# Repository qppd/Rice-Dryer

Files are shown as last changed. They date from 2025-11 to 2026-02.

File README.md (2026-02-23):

# RiceDryer ESP32 & Android IoT System

IoT-enabled Rice Dryer system with ESP32 hardware and Android application for remote monitoring and control via Firebase Realtime Database.

## Table of Contents

1. [Features](#features)
2. [Quick Start](#quick-start)
3. [System Architecture](#system-architecture)
4. [Hardware Components](#hardware-components)
5. [3D Models](#3d-models)
6. [Software Components](#software-components)
6. [Security and Credentials](#security-and-credentials)
7. [Installation Guide](#installation-guide)
8. [Device Pairing](#device-pairing)
9. [Usage Instructions](#usage-instructions)
10. [Code Structure](#code-structure)
11. [Firebase Database Structure](#firebase-database-structure)
12. [Android Application](#android-application)
13. [NTP Time Synchronization](#ntp-time-synchronization)
14. [Testing](#testing)
15. [Troubleshooting](#troubleshooting)
16. [Development Roadmap](#development-roadmap)
17. [Technical Specifications](#technical-specifications)
18. [Contributing](#contributing)
19. [License](#license)
20. [Contact](#contact)

## Features

### ESP32 Core Features

#### Hardware Control
- **3-Button Interface**: Setting mode toggle, start/stop control, WiFi reset functionality
- **Remote Setpoint Control**: Temperature/humidity setpoint adjustment via Android app (30-80°C, 10-50%)
- **Dual Relay System**: Independent heater (SSR1) and fan (SSR2) control for optimal drying
- **Smart Drying Logic**: Auto-stop when humidity target reached, PID temperature control
- **Safety Features**: Sensor error detection, force-stop capability, confirmation dialogs

#### Connectivity & Communication
- **WiFiManager Integration**: Easy WiFi configuration through captive portal (SSID: "RiceDryer_Setup")
- **Firebase Realtime Database**: Automatic device registration and real-time data synchronization
- **NTP Time Sync**: Network Time Protocol for accurate timestamps (Philippines timezone UTC+8)
- **Real-time Data Streaming**: Updates every 5 seconds (temperature, humidity, both setpoints, relay status)
- **Historical Data Logging**: Comprehensive sensor readings logged every 30 seconds
- **Remote Control**: Responds to START, STOP, SET_TEMP, SET_HUMIDITY commands
- **Device Pairing**: Secure 6-digit pairing code generation and validation

#### User Interface & Experience
- **Multi-Mode LCD Display**: Normal operation, setting modes, pairing mode, WiFi setup
- **Interactive Setting Modes**: Temperature setting mode, humidity setting mode with visual feedback
- **Mode Timeout Protection**: Auto-return to normal mode after 5 seconds of inactivity
- **Button Debouncing**: Reliable 200ms debounce for all button interactions
- **Status Indicators**: Real-time drying status, connectivity status, error notifications

#### Advanced Features
- **OTA Updates Support**: Over-the-air firmware updates with progress display
- **Automatic Reconnection**: Exponential backoff for WiFi and Firebase connections
- **Test Mode**: Component testing suite accessible at startup
- **WiFi Credential Reset**: Hold-to-confirm WiFi reset (3-second hold protection)
- **Sensor Validation**: DHT22 error detection with user notification

### Android App Features (95% Complete ✅)

- **Authentication System**: Email/password login, registration, password reset, session management
- **Multi-Device Support**: Manage multiple rice dryers from single account
- **Dashboard**: Real-time temperature/humidity gauges with animations, device status, heater/fan control
- **Charts and Analytics**: Interactive line charts with zoom/pan, time range filters (1h, 6h, 24h, 1 week), statistics
- **Device List Management**: View all paired devices, connection status, last update time
- **Device Pairing**: Secure 6-digit code pairing with validation and expiry check
- **Real-time Updates**: Firebase listeners for live data synchronization
- **Offline Support**: Local caching with Room database for offline access
- **Material Design 3**: Modern, professional UI following Material Design guidelines
- **Navigation**: Jetpack Compose Navigation with type-safe routing
- **Dark Theme Support**: Full Material You dynamic theming

## Quick Start

### Prerequisites

Hardware:
- ESP32 Development Board (38-pin dev module)
- DHT22 Temperature & Humidity Sensor
- 16x2 I2C LCD Display
- 2x Solid State Relays (SSR) - Heater (SSR1) + Fan (SSR2) control
- 3x Push Buttons (setting mode, start/stop, WiFi reset)
- Power supply and connecting wires
- Pull-up resistors (or use ESP32 internal pull-ups)

Software:
- Arduino IDE (1.8.19 or higher) OR PlatformIO
- Android Studio (latest version with Compose support)
- Firebase Account with Realtime Database enabled
- Git

### ESP32 Quick Setup

1. Clone Repository:
```bash
git clone https://github.com/qppd/Rice-Dryer.git
cd Rice-Dryer
```

2. Setup Firebase Credentials:
```bash
cd source/esp32/RiceDryer
copy FirebaseConfig.cpp.template FirebaseConfig.cpp
copy FirebaseConfig.h.template FirebaseConfig.h
```

3. Edit FirebaseConfig.cpp and FirebaseConfig.h with your Firebase credentials:
   - Get from Firebase Console > Project Settings > Service accounts
   - Update Firebase host, auth token, and database URL

4. Install Required Libraries in Arduino IDE:
   - WiFiManager by tzapu (v2.0.16-rc.2 or higher)
   - Firebase ESP32 Client by Mobizt (v4.4.14 or higher)
   - DHT sensor library by Adafruit (v1.4.6 or higher)
   - LiquidCrystal I2C (v1.1.2 or higher)
   - ArduinoJson (v6.21.5 or higher)

5. Configure Arduino IDE:
   - Board: ESP32 Dev Module
   - **Partition Scheme: "Minimal SPIFFS (1.9MB APP)" or "Huge APP (3MB No OTA)"** ⚠️ **CRITICAL**
   - Upload Speed: 921600
   - Flash Size: 4MB
   - Flash Mode: QIO
   - Flash Frequency: 80MHz

   **⚠️ IMPORTANT: Partition Scheme Selection**
   
   The default partition scheme (1.3MB APP) is **too small** for Firebase projects. You MUST change it:
   
   **For Arduino IDE 1.x:**
   - Go to Tools → Partition Scheme
   - Select "Minimal SPIFFS (1.9MB APP)" or "Huge APP (3MB No OTA)"
   
   **For Arduino IDE 2.x (if Partition Scheme not visible):**
   - See detailed instructions in "Arduino IDE 2.x Partition Fix" section below
   
   **Why this is required:**
   - Firebase ESP32 Client library is large (~150KB)
   - WiFiManager adds ~80KB
   - Total sketch size: ~420KB (32% of 1.3MB, 13% of 3MB)
   - Recommended: Use "Huge APP (3MB No OTA)" for maximum space

6. Upload to ESP32:
   - Open RiceDryer.ino in Arduino IDE
   - Verify/Compile (Ctrl+R)
   - Upload (Ctrl+U)

7. First Boot Sequence:
   - ESP32 creates WiFi AP: "RiceDryer_Setup" (password: password123)
   - Connect to AP from phone/computer
   - Captive portal opens automatically
   - Configure your WiFi credentials
   - ESP32 syncs time via NTP (Philippines timezone)
   - Firebase connection established
   - 6-digit pairing code displayed on LCD

### Android Quick Setup

1. Navigate to Android project:
```bash
cd source/android/RiceDryer
```

2. Setup Firebase for Android:
   - Get google-services.json from Firebase Console > Project Settings
   - Place in: `source/android/RiceDryer/app/google-services.json`

3. Open in Android Studio:
   - File > Open > select `source/android/RiceDryer` folder
   - Wait for Gradle sync to complete
   - Build > Rebuild Project

4. Run on Device/Emulator:
   - Connect Android device via USB (enable USB debugging)
   - Or start Android emulator
   - Run > Run 'app' (Shift+F10)
   - Register new account or login
   - Pair device using 6-digit code from LCD

### Verification Checklist

✅ Verify credentials are protected:
```bash
git status
# Should NOT show FirebaseConfig.cpp, FirebaseConfig.h, or google-services.json
```

✅ ESP32 Tests:
- LCD displays WiFi connected and IP address
- LCD shows "Time Synced" with current date/time (Philippines timezone)
- Firebase Ready message appears
- Pairing code (6 digits) displayed on LCD
- Temperature and humidity readings updating

✅ Android Tests:
- Login/Registration works
- Device pairing successful
- Dashboard shows real-time temperature/humidity
- START/STOP commands work
- Charts display historical data
- Device list shows paired devices

## System Architecture

The Rice Dryer system follows a modern IoT architecture with five distinct layers:

### 1. Hardware Layer
- ESP32 microcontroller (38-pin dev module)
- DHT22 temperature and humidity sensor
- 16x2 I2C LCD display (0x27 address)
- 2x Solid State Relays (Heater on GPIO 26, Fan on GPIO 27)
- 3x Push buttons with debouncing

### 2. Firmware Layer (ESP32)
- Arduino C++ based firmware
- WiFiManager for network configuration
- Firebase ESP32 Client for cloud connectivity
- NTP time synchronization (Philippines UTC+8)
- PID temperature controller
- Real-time sensor reading and control logic

### 3. Cloud Layer (Firebase)
- Firebase Realtime Database for data storage and synchronization
- Firebase Authentication for user management
- Secure device pairing mechanism
- Real-time data streaming
- Historical data storage (30-second intervals)

### 4. Application Layer (Android)
- Kotlin with Jetpack Compose
- MVVM architecture pattern
- Repository pattern for data management
- Kotlin Coroutines and Flow for async operations
- Room database for local caching
- Material Design 3 UI components

### 5. User Interface Layer
- Dashboard with animated circular gauges

- Historical data charts
- Device management interface
- Profile and settings

## Hardware Components

### Complete Bill of Materials

The Rice Dryer system consists of the following components, organized by category:

#### 🔧 Electronics & Control

**Microcontroller & Development:**
- ESP32 38-pin Development Board
  - Clock Speed: 240 MHz dual-core
  - Flash Memory: 4MB
  - WiFi: 802.11 b/g/n
  - Operating Voltage: 3.3V
  - Source: [ESP32 38-pin Dev Board](https://www.lazada.com.ph/products/pdp-i229344573-s15172858004.html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)

**Sensors:**
- DHT22 Temperature & Humidity Sensor
  - Temperature Range: -40°C to 80°C (±0.5°C accuracy)
  - Humidity Range: 0-100% RH (±2-5% accuracy)
  - Sampling Rate: 0.5 Hz (once every 2 seconds)
  - Source: [DHT22 Sensor](https://www.lazada.com.ph/products/pdp-i132179919.html)

**Display:**
- I2C LCD 20x4 Display
  - Display: 20 characters x 4 lines
  - Backlight: Blue LED
  - Interface: I2C (SDA, SCL)
  - Address: 0x27 or 0x3F
  - Source: [I2C LCD 20x4](https://www.lazada.com.ph/products/pdp-i230446570-s1630476280.html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)

**Control Components:**
- 2x 1-Channel Relay Modules with Optocoupler
  - Control Voltage: 3-32V DC
  - Load Voltage: 5-250V AC/DC
  - Load Current: 10A maximum
  - Isolation: Optocoupler protection
  - Source: [1-Channel Relay Module](https://www.lazada.com.ph/products/pdp-i100047427-s100061336.html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)
- 10K Potentiometer (Linear)
  - Resistance: 10KΩ
  - Type: Rotary potentiometer
  - Usage: Temperature/humidity setpoint adjustment
- 3x Push Button Switches (Momentary)
  - Type: SPST momentary contact
  - Rating: 12V/1A
  - Usage: Control interface buttons
  - Source: [Tactile Push Buttons](https://www.lazada.com.ph/products/pdp-i1678078643-s7245702074.html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)

#### ⚡ Power & Heating System

**Heating & Ventilation:**
- 2x 12V Exhaust Fans
  - Model: HF DC BRUSHLESS FAN 120mm DF1202512SEL
  - Voltage: 12V DC
  - Current: 0.16A each
  - Power: 1.92W each
  - Airflow: 50 CFM (estimated)
  - Source: [HF DC BRUSHLESS FAN 120mm](https://www.lazada.com.ph/products/pdp-i3534864736.html)
  - Usage: Air circulation and moisture removal
- 12V Heating Element (Salvaged and Modified)
  - Voltage: 12V DC
  - Power: 35W (tested)
  - Type: Modified car hair dryer heating element (2 elements remaining from original 6)
  - Source: [12V Car Folding Hair Drier](https://www.lazada.com.ph/products/i4960365287-s28954002950.html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)
  - Usage: Primary heating source

**Power Management:**
- MPPT Solar Charge Controller
  - Model: MPPT 30A/50A/100A 12V/24V Auto Focus Tracking Solar Panel Charge Controller Regulator with Dual
  - Input Voltage: 12-150V DC (estimated)
  - Output Voltage: 12V/24V DC
  - Current Options: 30A, 50A, 100A
  - Type: MPPT (Maximum Power Point Tracking)
  - Efficiency: High efficiency auto focus tracking
  - Source: [MPPT Solar Charge Controller](https://www.lazada.com.ph/products/pdp-i4841729811-s28068159465.html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)
  - Usage: Solar panel charge regulation for battery charging
- 12V Deep Cycle Gel Battery
  - Model: High-Quality 12V Deep Cycle Gel E-Bike Battery 16AH/25AH for Scooters and Motorcycles
  - Voltage: 12V
  - Capacity Options: 16AH, 25AH
  - Type: Sealed lead-acid gel battery (deep cycle)
  - Cycle Life: High cycle life for deep discharge
  - Source: [12V Gel Battery](https://www.lazada.com.ph/products/high-quality-12v-deep-cycle-gel-e-bike-battery-16ah25ah-for-scooters-and-motorcycles-i4913678464-s28636228269.html)
  - Usage: Energy storage for the 12V system
- SPST KCD11 Miniature Rocker Switch
  - Model: SPST KCD11 Miniature Rocker Switch - 5Pcs
  - Type: SPST rocker switch (2 Pin or 3 Pin options)
  - Rating: 12V/10A (estimated)
  - Illumination: Red LED indicator (if applicable)
  - Quantity: 5 pieces
  - Source: [Rocker Switch](https://www.lazada.com.ph/products/pdp-i3015510213-s14819033850.html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)
  - Usage: Power switch for the 12V system
- 12V Power Adapter
  - Output Options: 12V 2A
  - Type: True rated power adapter
  - Source: [12V 2A Power Adapter](https://www.lazada.com.ph/products/i136286593-s153295621.html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)
  - Usage: Main power supply for 12V system

#### 🏗️ Mechanical & Enclosure

**Structural Materials:**
- 1/2" Nebraska Plywood Sheets
  - Thickness: 12mm (1/2 inch)
  - Size: 4ft x 8ft sheets
  - Type: Marine-grade plywood
  - Usage: Main enclosure construction
- Tek Screws (Assorted)
  - Sizes: #6, #8, #10
  - Length: 1/2" to 2"
  - Type: Self-tapping screws
  - Quantity: 200 pieces
- Nails (Assorted)
  - Sizes: 1", 1.5", 2"
  - Type: Common nails
  - Quantity: 500 pieces

**Prototyping:**
- Perf Board (Prototype Board)
  - Size: 2" x 3"
  - Hole Pattern: 0.1" grid
  - Copper Pads: Plated through holes
  - Usage: Custom circuit prototyping
  - Source: [Perf Board](https://www.lazada.com.ph/products/pdp-i4835206547-s28752341734.html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)

### Wiring Diagram

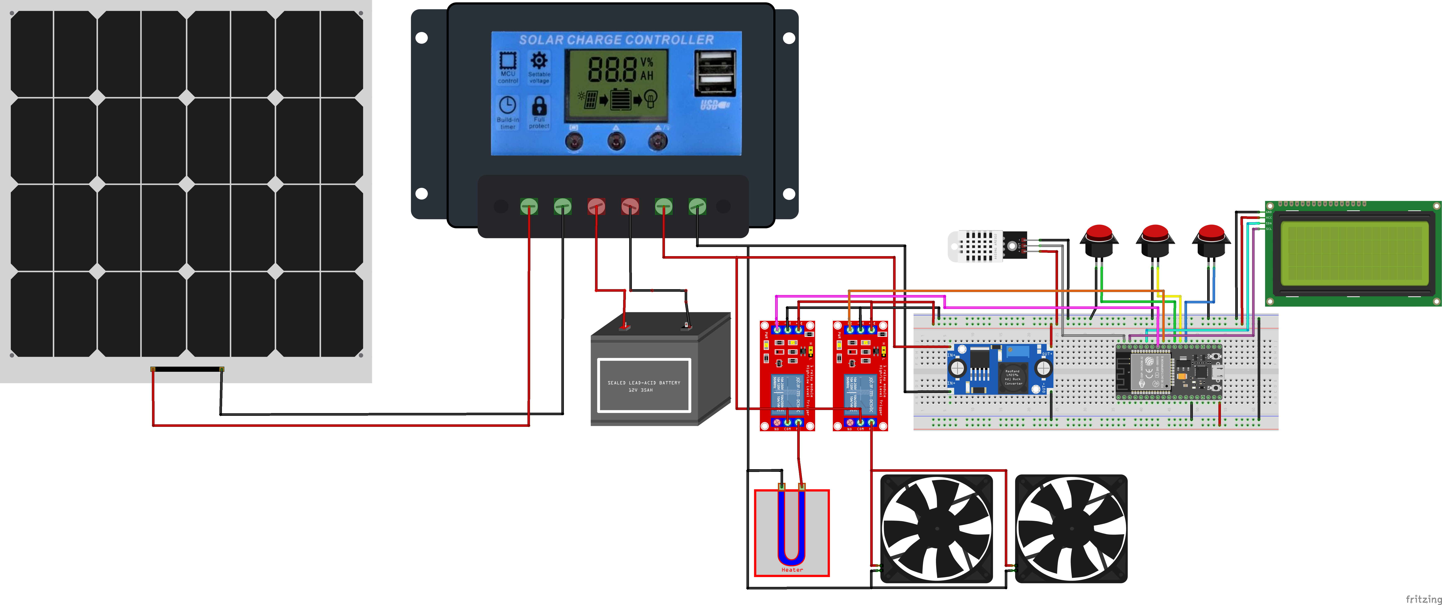
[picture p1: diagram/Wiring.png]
Rice Dryer Wiring Diagram


**Download Fritzing File:** [Wiring.fzz](diagram/Wiring.fzz)

### MakerLab Electronics Components

The following components were sourced from [MakerLab Electronics](https://makerlab-electronics.com) and are available on Lazada Philippines:

**✅ Available at MakerLab on Lazada:**
- [ESP32 38-pin Development Board](https://www.lazada.com.ph/products/pdp-i229344573.html)
- [DHT22 Temperature & Humidity Sensor](https://www.lazada.com.ph/products/pdp-i132179919.html)
- [I2C LCD 20x4 Display](https://www.lazada.com.ph/products/pdp-i230446570.html)
- [1-Channel Relay Modules with Optocoupler (2x required)](https://www.lazada.com.ph/products/pdp-i100047427.html)

- [Push Button Switches (3x required)](https://www.lazada.com.ph/products/pdp-i3015053765.html)

### Cost Estimate & Sourcing

**Estimated Total Cost: ₱8,170 - ₱11,500**

**By Component Category:**

**Electronics (MakerLab): ₱2,500 - ₱3,500**
- ESP32 Dev Board: ₱450
- DHT22 Sensor: ₱150
- 20x4 I2C LCD: ₱350
- 2x Relay Modules: ₱200 each = ₱400
- 10K Potentiometer: ₱25
- 3x Push Buttons: ₱15 each = ₱45
- Perf Board: ₱50

**Power & Heating System: ₱4,000 - ₱6,000**
- 2x 12V Exhaust Fans: ₱250 each = ₱500
- 12V Heating Element: ₱800
- 12V Solar Charge Controller: ₱1,200
- 12V 16AH Gel Battery: ₱2,500
- Rocker Switch: ₱50

**Mechanical & Enclosure: ₱1,670 - ₱2,000**
- 1/2" Nebraska Plywood (4x8 sheet): ₱980
- Tek Screws (assorted): ₱50
- Nails (assorted): ₱50
- Hinges (2 pcs): ₱70 each = ₱140
- Miscellaneous hardware: ₱450

### Main Components

ESP32 Development Module:
- Clock Speed: 240 MHz dual-core
- Flash Memory: 4MB
- WiFi: 802.11 b/g/n
- Operating Voltage: 3.3V

DHT22 Temperature and Humidity Sensor:
- Temperature Range: -40°C to 80°C (±0.5°C accuracy)
- Humidity Range: 0-100% RH (±2-5% accuracy)
- Sampling Rate: 0.5 Hz (once every 2 seconds)

16x2 I2C LCD Display:
- Display: 20 characters x 4 lines
- Backlight: Blue LED
- Interface: I2C (SDA, SCL)
- Address: 0x27 or 0x3F
- Note: System uses 20x4 LCD for enhanced display

Solid State Relay (SSR):
- Control Voltage: 3-32V DC
- Control Current: 5-25 mA
- Load Voltage: 24-380V AC
- Load Current: 25A continuous
- Switching Time: 10ms
- Zero-crossing: Yes
- Trigger Type: Low trigger (active low)

Additional Components:
- Push Button: Manual control and mode selection
- Power Supply: 5V/2A for ESP32 and peripherals
- Solar Panel (Optional): 12V/10W for off-grid operation

### Pin Connections (PinConfig.h) - Updated Configuration

DHT22 Sensor:
- VCC  -> 3.3V
- GND  -> GND
- DATA -> GPIO 39 (Input-only, perfect for sensor)

LCD (I2C):
- VCC -> 5V
- GND -> GND
- SDA -> GPIO 21
- SCL -> GPIO 22

Relay Controls:
- Relay 1 (Main Heater) -> GPIO 19
- Relay 2 (Fan/Secondary) -> GPIO 18
- VCC -> 3.3V/5V (depending on relay module)
- GND -> GND

Control Buttons:
- Button 1 (Setting Mode) -> GPIO 17 + GND (internal pull-up)
- Button 2 (Start/Stop) -> GPIO 16 + GND (internal pull-up)
- Button 3 (WiFi Reset) -> GPIO 4 + GND (internal pull-up)

## 3D Models

The Rice Dryer features a professional 3D-designed enclosure with optimized component placement and airflow design.

### Enclosure Views

#### Full Assembly Views
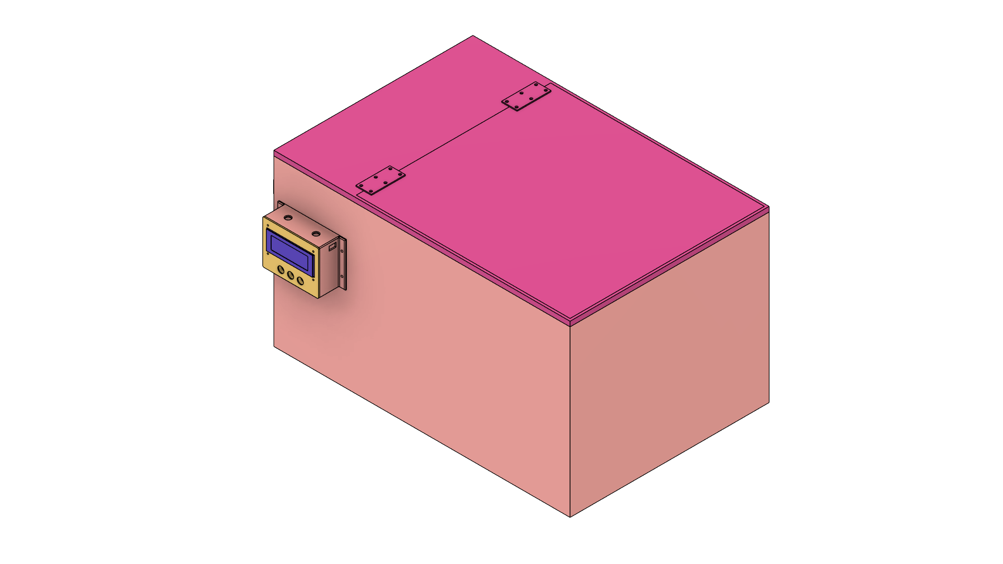
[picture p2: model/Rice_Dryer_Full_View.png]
Rice Dryer Full View

*Complete assembly with all components installed*

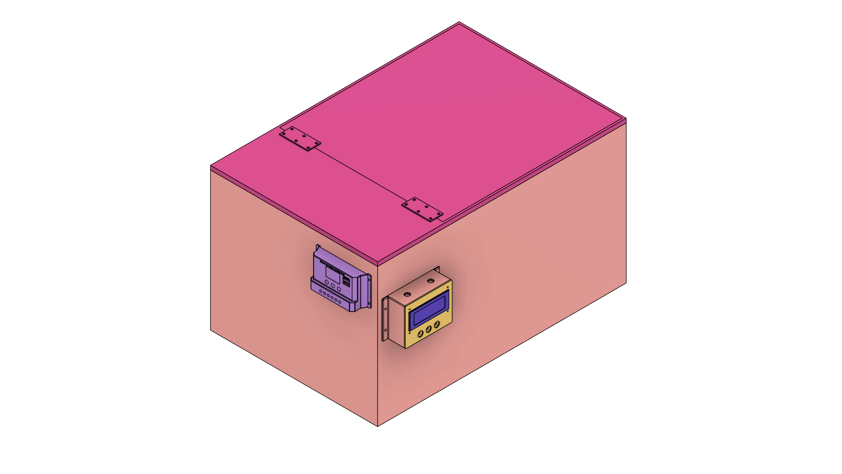
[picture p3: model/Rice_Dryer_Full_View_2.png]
Rice Dryer Full View 2

*Alternative full view showing different angle*

#### Internal Component Views
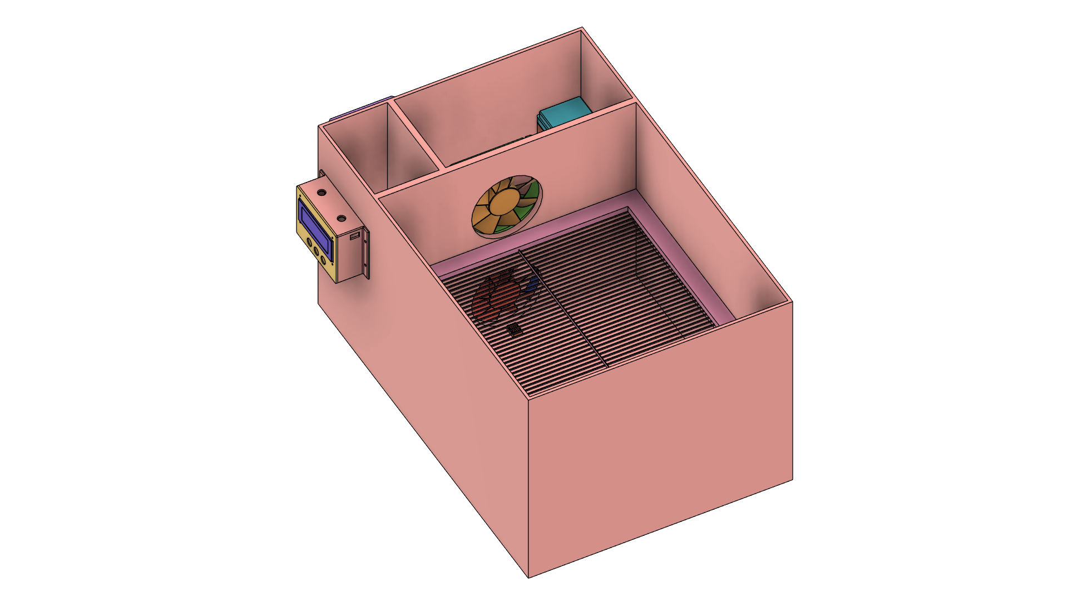
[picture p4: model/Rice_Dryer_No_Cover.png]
Rice Dryer No Cover

*Internal layout without top cover*

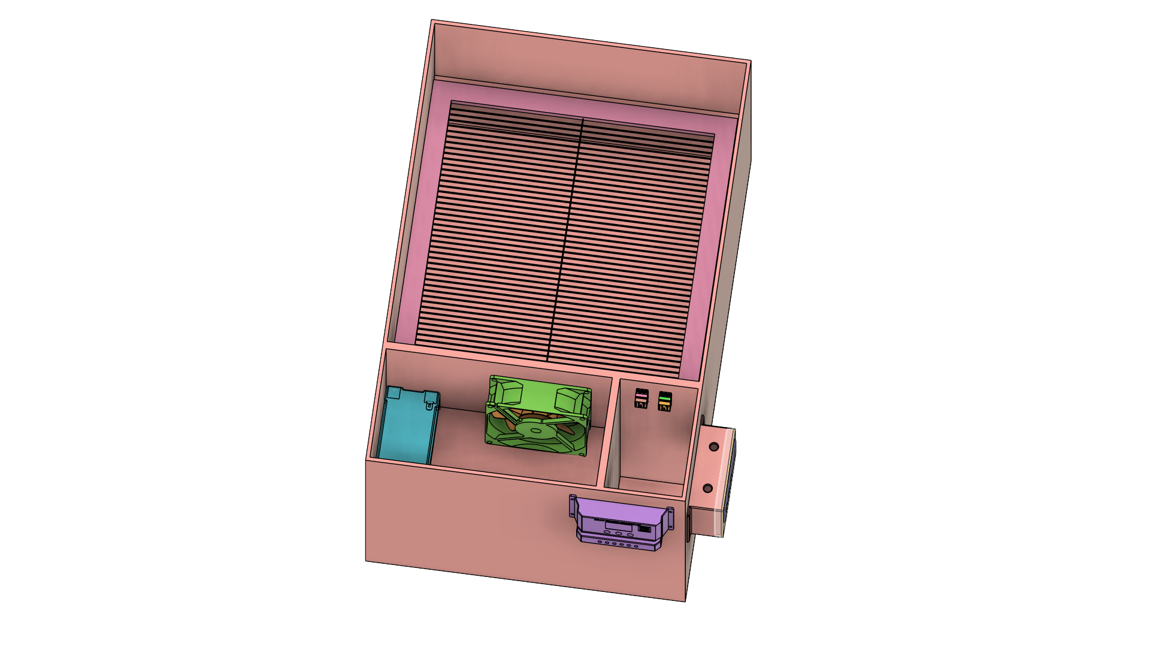
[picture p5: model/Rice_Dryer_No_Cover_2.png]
Rice Dryer No Cover 2

*Detailed internal component arrangement*

#### Orthogonal Views
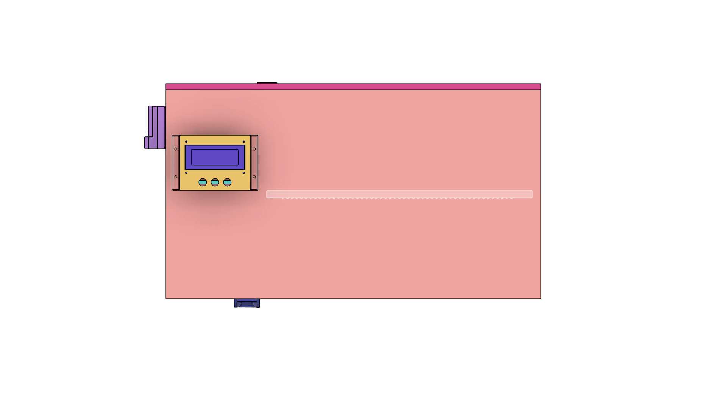
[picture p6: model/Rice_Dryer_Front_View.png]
Rice Dryer Front View

*Front elevation view*

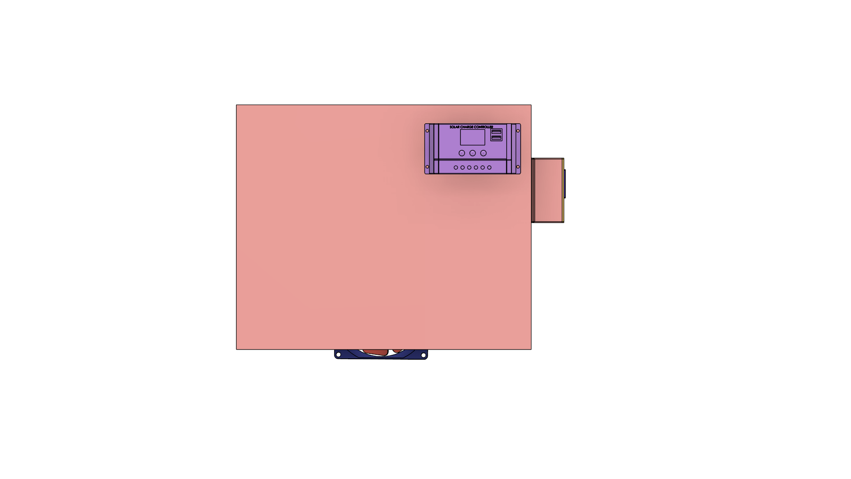
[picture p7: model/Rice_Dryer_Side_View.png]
Rice Dryer Side View

*Side elevation view*

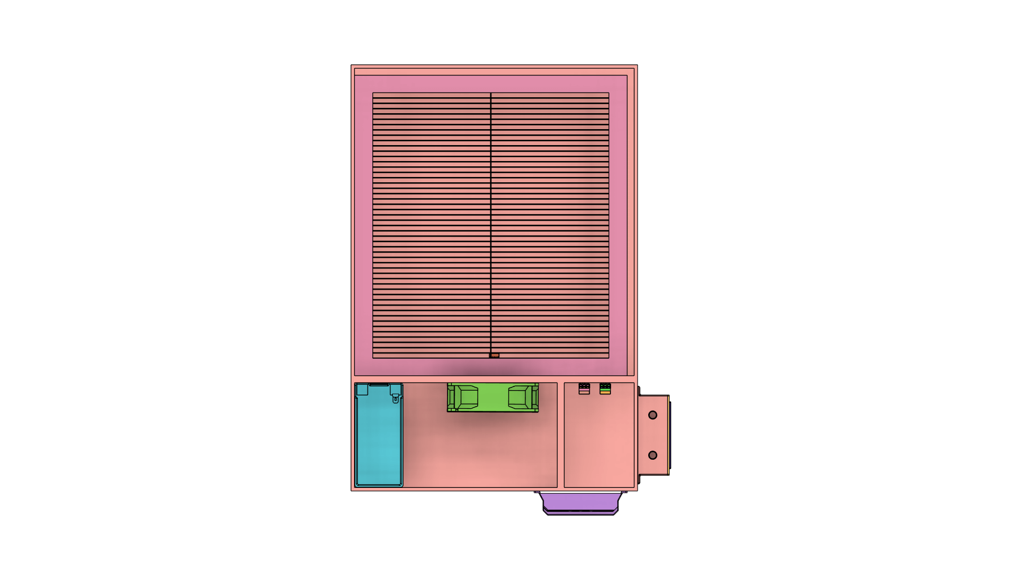
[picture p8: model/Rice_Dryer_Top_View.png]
Rice Dryer Top View

*Top plan view*

### Design Features

- **Optimized Airflow**: Strategic fan placement for efficient moisture removal
- **Component Accessibility**: Easy access panels for maintenance
- **Professional Finish**: Clean aesthetic with functional design
- **Modular Construction**: Easy assembly and disassembly
- **Thermal Management**: Proper ventilation for electronic components

## Software Components

### ESP32 Libraries

Core Libraries:
- WiFi.h (built-in): WiFi connectivity
- WiFiManager.h: Captive portal configuration
- Firebase_ESP_Client.h: Firebase integration
- ArduinoOTA.h (built-in): Over-the-air updates
- ArduinoJson.h: JSON parsing

Sensor Libraries:
- DHT.h: DHT22 sensor interface
- LiquidCrystal_I2C.h: LCD display control

Custom Modules:
- FirebaseConfig: Credential management
- WiFiManagerCustom: WiFi connection wrapper
- Button: Button debouncing and state management
- DHT22Sensor: Temperature/humidity reading
- SSR: Relay control
- LCDDisplay: Display management

### Android Dependencies

Core Android:
- androidx.appcompat:appcompat:1.6.1
- com.google.android.material:material:1.11.0
- androidx.constraintlayout:constraintlayout:2.1.4

Firebase (BOM 32.7.0):
- firebase-auth: User authentication
- firebase-database: Realtime Database
- firebase-messaging: Push notifications
- firebase-analytics: Usage tracking
- firebase-crashlytics: Crash reporting

Architecture Components:
- lifecycle-viewmodel:2.7.0
- lifecycle-livedata:2.7.0
- navigation-fragment:2.7.6
- navigation-ui:2.7.6

Database:
- room-runtime:2.6.1
- room-compiler:2.6.1

Charts and UI:
- MPAndroidChart:v3.1.0
- Lottie:6.3.0
- Glide:4.16.0
- Shimmer:0.5.0

### Project Structure

```
Rice-Dryer/
├── source/
│   ├── esp32/
│   │   ├── .gitignore
│   │   └── RiceDryer/
│   │       ├── RiceDryer.ino
│   │       ├── FirebaseConfig.cpp (gitignored)
│   │       ├── FirebaseConfig.h (gitignored)
│   │       ├── FirebaseConfig.cpp.template
│   │       ├── FirebaseConfig.h.template
│   │       ├── WiFiManagerCustom.cpp
│   │       ├── WiFiManagerCustom.h
│   │       ├── Button.cpp/h
│   │       ├── DHT22Sensor.cpp/h
│   │       ├── LCDDisplay.cpp/h
│   │       ├── SSR.cpp/h
│   │       └── PinConfig.h
│   │
│   └── android/
│       ├── .gitignore
│       └── app/
│           ├── build.gradle
│           ├── google-services.json (gitignored)
│           ├── google-services.json.template
│           └── src/main/java/com/qppd/ricedryer/
│               ├── data/
│               │   ├── model/
│               │   │   ├── User.java
│               │   │   ├── Device.java
│               │   │   ├── SensorReading.java
│               │   │   └── Command.java
│               │   ├── remote/
│               │   │   ├── FirebaseAuthManager.java
│               │   │   └── FirebaseDataSource.java
│               │   └── repository/
│               │       ├── AuthRepository.java
│               │       └── DeviceRepository.java
│               ├── ui/
│               │   ├── auth/
│               │   │   ├── LoginActivity.java
│               │   │   ├── AuthViewModel.java
│               │   │   └── activity_login.xml
│               │   └── [other activities/fragments]
│               └── utils/
│                   ├── Constants.java
│                   ├── DateUtils.java
│                   └── ValidationUtils.java
│
├── .gitignore
├── README.md
└── [documentation files]
```

## Security and Credentials

### Overview

This project implements enterprise-grade security with multi-layer protection for sensitive credentials. All API keys, Firebase credentials, and configuration files are properly protected from version control.

### Critical Files (NEVER COMMIT)

ESP32 Credentials:
- source/esp32/RiceDryer/FirebaseConfig.cpp
- source/esp32/RiceDryer/FirebaseConfig.h

Android Credentials:
- source/android/app/google-services.json
- source/android/app/*.keystore
- source/android/app/*.jks

### Multi-Layer Protection

We have implemented three levels of .gitignore protection:

Level 1 - Root .gitignore:
- Covers entire project
- Blocks all credential files globally
- Protects build artifacts and IDE files
- 200+ patterns for comprehensive coverage

Level 2 - ESP32 .gitignore:
- Located: source/esp32/.gitignore
- Blocks FirebaseConfig.cpp and FirebaseConfig.h
- Protects compiled binaries and build artifacts

Level 3 - Android .gitignore:
- Located: source/android/.gitignore
- Blocks google-services.json
- Protects keystore files and signing configurations

### Modular Architecture

Following the Smart Fan project pattern, credentials are separated into dedicated modules:

FirebaseConfig Module:
- FirebaseConfig.h: Method declarations
- FirebaseConfig.cpp: Implementation with actual credentials (gitignored)
- FirebaseConfig.h.template: Safe template for new developers
- FirebaseConfig.cpp.template: Safe template for new developers

Benefits:
- Credentials separated from main code
- Easy to update without touching main sketch
- Template files guide new developers
- Clean, professional code structure

### Setup Process for New Developers

1. Clone repository:
```bash
git clone https://github.com/qppd/Rice-Dryer.git
cd Rice-Dryer
```

2. Setup ESP32 credentials:
```bash
cd source/esp32/RiceDryer
copy FirebaseConfig.cpp.template FirebaseConfig.cpp
copy FirebaseConfig.h.template FirebaseConfig.h
```

3. Get credentials from Firebase Console:
   - Go to Project Settings
   - Download google-services.json
   - Extract values:
     - project_id
     - firebase_url
     - current_key (API key)

4. Edit FirebaseConfig.cpp:
```cpp
const char* FirebaseConfig::getFirebaseHost() {
    return "YOUR-PROJECT-default-rtdb.firebaseio.com";
}

const char* FirebaseConfig::getFirebaseAuth() {
    return "YOUR_API_KEY";
}

const char* FirebaseConfig::getDatabaseURL() {
    return "https://YOUR-PROJECT-default-rtdb.firebaseio.com";
}

const char* FirebaseConfig::getProjectId() {
    return "YOUR-PROJECT-ID";
}
```

5. Setup Android credentials:
   - Place google-services.json in: source/android/app/google-services.json

6. Verify protection:
```bash
git status
# FirebaseConfig.cpp and google-services.json should NOT appear
```

### Security Best Practices

DO:
- Use template files for credentials
- Keep credentials in .gitignore
- Share credentials through secure channels (not git)
- Rotate API keys regularly
- Use different credentials for dev/prod
- Verify .gitignore before committing

DON'T:
- Commit credential files to git
- Share credentials in public channels
- Hardcode credentials in source files
- Push google-services.json to remote
- Commit keystore files
- Use production keys in development

### Verification Commands

Check if credentials are tracked:
```bash
git ls-files | grep -E "(FirebaseConfig\.(cpp|h)|google-services\.json)"
# Should return NOTHING
```

Check git status:
```bash
git status
# Credential files should not appear
```

Verify .gitignore is working:
```bash
git check-ignore -v source/esp32/RiceDryer/FirebaseConfig.cpp
git check-ignore -v source/android/app/google-services.json
# Should show which .gitignore rule is blocking them
```

### Emergency: Credentials Exposed

If credentials are accidentally committed:

1. Immediately remove from git history:
```bash
git filter-branch --force --index-filter \
  "git rm --cached --ignore-unmatch path/to/credential/file" \
  --prune-empty --tag-name-filter cat -- --all
```

2. Regenerate all exposed credentials:
   - Go to Firebase Console
   - Regenerate API keys
   - Update all local copies
   - Inform team members

3. Force push (if using remote):
```bash
git push origin --force --all
```

### Pre-Commit Checklist

Before every commit:
- [ ] Run git status - no credential files
- [ ] Check diff with git diff - no API keys visible
- [ ] Verify .gitignore is updated
- [ ] Test build works with templates
- [ ] Review file list in git add

## Installation Guide

### ESP32 Installation

1. Install Arduino IDE:
   - Download from arduino.cc
   - Install version 1.8.19 or higher

2. Add ESP32 Board Support:
   - File > Preferences
   - Additional Board Manager URLs: https://dl.espressif.com/dl/package_esp32_index.json
   - Tools > Board > Boards Manager
   - Search "ESP32" and install

3. Install Required Libraries:
   Open Arduino IDE Library Manager (Sketch > Include Library > Manage Libraries):
   - WiFiManager by tzapu
   - Firebase ESP32 Client by Mobizt
   - DHT sensor library by Adafruit
   - Adafruit Unified Sensor
   - LiquidCrystal I2C by Frank de Brabander
   - ArduinoJson by Benoit Blanchon

4. Setup Credentials:
   ```bash
   cd source/esp32/RiceDryer
   copy FirebaseConfig.cpp.template FirebaseConfig.cpp
   copy FirebaseConfig.h.template FirebaseConfig.h
   ```
   Edit FirebaseConfig.cpp with your Firebase credentials

5. Configure Board:
   - Tools > Board > ESP32 Arduino > ESP32 Dev Module
   - Tools > Upload Speed > 115200
   - Tools > Flash Frequency > 80MHz
   - Tools > Flash Size > 4MB
   - Tools > Partition Scheme > Default 4MB with spiffs

6. Compile and Upload:
   - Open source/esp32/RiceDryer/RiceDryer.ino
   - Click Verify to compile
   - Connect ESP32 via USB
   - Select correct COM port
   - Click Upload

### Android Installation

1. Install Android Studio:
   - Download from developer.android.com
   - Install latest stable version

2. Setup Firebase:
   - Go to Firebase Console (console.firebase.google.com)
   - Select your project
   - Project Settings > Download google-services.json
   - Place in: source/android/app/google-services.json

3. Open Project:
   - Android Studio > File > Open
   - Navigate to source/android folder
   - Click OK
   - Wait for Gradle sync to complete

4. Configure Build:
   - Build > Make Project
   - Fix any errors (should be none if setup correctly)

5. Run on Device:
   - Enable Developer Options on Android device
   - Enable USB Debugging
   - Connect device via USB
   - Run > Run 'app'
   - Select connected device
   - Wait for installation

### Firebase Configuration

1. Create Firebase Project:
   - Go to console.firebase.google.com
   - Click "Add project"
   - Enter project name
   - Enable Google Analytics (optional)

2. Setup Realtime Database:
   - Build > Realtime Database
   - Create database
   - Start in test mode (temporary)
   - Note database URL

3. Setup Authentication:
   - Build > Authentication
   - Sign-in method > Email/Password
   - Enable Email/Password authentication

4. Setup Security Rules:
```json
{
  "rules": {
    "users": {
      "$userId": {
        ".read": "$userId === auth.uid",
        ".write": "$userId === auth.uid"
      }
    },
    "devices": {
      "$deviceId": {
        ".read": "root.child('devices').child($deviceId).child('deviceInfo').child('pairedTo').val() === auth.uid",
        ".write": "root.child('devices').child($deviceId).child('deviceInfo').child('pairedTo').val() === auth.uid || auth.uid === null"
      }
    }
  }
}
```

5. Download Configuration Files:
   - For Android: google-services.json
   - Extract credentials for ESP32 FirebaseConfig

### Arduino IDE 2.x Partition Fix

If you're using Arduino IDE 2.x and don't see "Partition Scheme" in the Tools menu:

#### Solution 1: Edit boards.txt (Recommended)
1. Navigate to:
   ```
   Windows: C:\Users\<YourUsername>\AppData\Local\Arduino15\packages\esp32\hardware\esp32\<version>\boards.txt
   ```
2. Find your board section (search for `esp32.name=ESP32 Dev Module`)
3. Look for the line: `esp32.build.partitions=default`
4. Change it to: `esp32.build.partitions=huge_app`
5. Save file and restart Arduino IDE

#### Solution 2: Use platform.local.txt (Cleaner)
1. Navigate to:
   ```
   C:\Users\<YourUsername>\AppData\Local\Arduino15\packages\esp32\hardware\esp32\<version>\
   ```
2. Create a new file named: `platform.local.txt`
3. Add this line: `build.partitions=huge_app`
4. Save and restart Arduino IDE

#### Solution 3: Switch to PlatformIO (Alternative)
If using VS Code with PlatformIO extension:
```ini
[env:esp32dev]
platform = espressif32
board = esp32dev
framework = arduino
board_build.partitions = huge_app.csv
monitor_speed = 115200

lib_deps = 
    mobizt/Firebase Arduino Client Library for ESP8266 and ESP32
    adafruit/DHT sensor library
    marcoschwartz/LiquidCrystal_I2C
    tzapu/WiFiManager
```

### ESP32 Firmware Operation Modes

The RiceDryer firmware supports two compile-time operation modes:

#### 🚀 PRODUCTION MODE (Default)
Full production firmware with all features for actual rice drying operations.

**Features Enabled:**
- ✅ WiFi Manager with captive portal
- ✅ Firebase Realtime Database sync
- ✅ Device Pairing system
- ✅ PID Temperature Control
- ✅ Auto-stop at target humidity
- ✅ 3-Button UI (Normal/Set Temp/Set Humidity modes)
- ✅ Remote Commands from Android app
- ✅ Historical Data Logging (30-second intervals)
- ✅ NTP Time Synchronization (Philippines UTC+8)
- ✅ Safety Logic & sensor validation

**Button Functions:**
- **Button 1 (GPIO 17):** Toggle mode (Normal → Set Temp → Set Humidity)
- **Button 2 (GPIO 16):** Start/Stop drying (or increase setpoint in setting modes)
- **Button 3 (GPIO 4):** Factory reset (hold 5s) or decrease setpoint

#### 🔧 DEVELOPMENT MODE
Isolated hardware testing without requiring WiFi/Firebase configuration.

**Purpose:** Testing individual hardware components before full deployment.

**Features Enabled:**
- ✅ LCD Display (20x4 I2C, address 0x27)
- ✅ DHT22 Sensor (GPIO 23)
- ✅ Heater Relay (GPIO 19)
- ✅ Blower Relay (GPIO 18)
- ✅ Serial Command Interface (115200 baud)

**Features Disabled:**
- ❌ WiFi & Captive Portal
- ❌ Firebase & Pairing System
- ❌ PID Temperature Control
- ❌ Drying Start/Stop Logic
- ❌ 3-Button UI Modes
- ❌ Remote Commands

**How to Enable:**
1. Open `RiceDryer.ino`
2. Locate line 28: `//#define DEVELOPMENT_MODE`
3. Uncomment: `#define DEVELOPMENT_MODE`
4. Upload firmware

**Available Serial Commands (115200 baud):**
```
HELP                 - Show all commands
STATUS               - Show hardware status
LCD_TEST             - Test all LCD lines
LCD_CLEAR            - Clear LCD display
LCD_PRINT:<text>     - Custom LCD text
DHT_READ             - Read temperature & humidity
RELAY_HEATER_ON      - Turn heater relay ON (GPIO 19 → LOW)
RELAY_HEATER_OFF     - Turn heater relay OFF (GPIO 19 → HIGH)
RELAY_BLOWER_ON      - Turn blower relay ON (GPIO 18 → LOW)
RELAY_BLOWER_OFF     - Turn blower relay OFF (GPIO 18 → HIGH)
```

**LCD Display in Development Mode:**
```
DEVELOPMENT MODE
Hardware Test
Open Serial @115200
Type HELP
```

**Example Test Session:**
```
> HELP
=== DEVELOPMENT MODE COMMANDS ===
(Lists all available commands)

> LCD_TEST
LCD test executed

> DHT_READ
Temperature: 28.3 C, Humidity: 65.2 %

> RELAY_HEATER_ON
Heater relay (GPIO 19) turned ON

> STATUS
Heater Relay (GPIO 19): ON
Blower Relay (GPIO 18): OFF
Temperature: 28.3 C
Humidity: 65.2 %
```

**Switching Back to Production Mode:**
1. Edit `RiceDryer.ino` line 28
2. Comment: `//#define DEVELOPMENT_MODE`
3. Upload firmware

### Code Size Optimization Notes

The firmware has been optimized to fit within ESP32 flash constraints:

**Optimizations Applied:**
- ❌ OTA update functionality removed (~30-50KB saved)
- ❌ Serial debug output removed (~10-15KB saved)
- ❌ Test mode functions removed (~5-8KB saved)
- ✅ All Firebase functionality preserved
- ✅ WiFiManager retained (minimal version)
- ✅ All core features intact

**Total Savings:** ~50-80KB

**Current Sketch Size:**
- With default partition (1.3MB): ~95% usage
- With "Huge APP (3MB)": ~38% usage

**If Still Too Large:**
1. Change partition scheme (most important - see above)
2. Remove historical data logging (saves ~15KB)
3. Reduce Firebase update frequencies
4. Consider ESP32 with 8MB or 16MB flash

## Device Pairing

### Pairing Process

1. ESP32 First Boot:
   - Device generates random 6-digit pairing code
   - Code displayed on LCD for 10 minutes
   - Code stored in Firebase: /devicePairing/{code}/

2. Android App Pairing:
   - Open app and login
   - Navigate to Devices screen
   - Tap "Add Device" button (floating action button)
   - Enter 6-digit code from ESP32 LCD
   - Give device a friendly name
   - Tap "Pair Device"

3. Verification:
   - App validates code against Firebase
   - Associates device with user account
   - Updates device status to "Paired"
   - Code expires and becomes invalid

4. Success:
   - Device appears in devices list
   - Real-time data starts streaming
   - Remote control enabled
   - LCD shows "Paired" status

### Troubleshooting Pairing

Code Expired:
- Pairing codes expire after 10 minutes
- Press reset button on ESP32 to generate new code

Code Invalid:
- Ensure correct 6-digit code (case-sensitive numbers)
- Check LCD display for current code
- Verify ESP32 is connected to WiFi and Firebase

Connection Issues:
- ESP32 must be online (check LCD status)
- Android device needs internet connection
- Verify Firebase Realtime Database is accessible

## Usage Instructions

### ESP32 Operation

#### Button Controls

**Button 1 (GPIO 17) - Setting Mode Toggle:**
- **Single Press**: Cycles through setting modes:
  - Normal Mode → Set Temperature Mode → Set Humidity Mode → Normal Mode
- **Auto-timeout**: Returns to normal mode after 5 seconds of inactivity

**Button 2 (GPIO 16) - Start/Stop Control:**
- **Press**: Toggle drying process on/off
- **Start**: Begins automatic drying until humidity setpoint is reached
- **Stop**: Force-stops drying immediately (safety override)

**Button 3 (GPIO 4) - WiFi Reset:**
- **Hold 3 seconds**: Resets WiFi credentials and restarts device
- **Short press**: Cancels reset operation (safety feature)

#### Display Modes

**1. Normal Mode:**
```
Drying: ON/OFF
T:25.5 H:45.2
```

**2. Set Temperature Mode:**
```
Set Temperature:
65.0C (Use Android App)
```

**3. Set Humidity Mode:**
```
Set Humidity:
20.0% (Use Android App)
```

**4. Pairing Mode:**
```
Pairing Code:
XXXXXX
MAC Address:
AABBCCDDEEFF
```

#### Drying Logic

**Automatic Operation:**
1. User sets temperature setpoint via Android app
2. User sets humidity target via Android app
3. User starts drying (Button 2)
4. System heats to temperature setpoint using Relay 1
5. Fan runs continuously via Relay 2 for air circulation
6. Drying stops automatically when humidity ≤ target
7. User can force-stop anytime with Button 2

**Safety Features:**
- Sensor error detection stops operation
- WiFi reset requires 3-second hold
- Mode timeout prevents accidental setting changes
- Force-stop capability overrides automatic operation

#### Startup & Test Mode

**Normal Startup:**
- Display: "Rice Dryer v1.0" → Current setpoints → Normal operation

**Test Mode (Hold Button 1 during startup):**
- Component testing suite
- Tests: DHT22, Relays, LCD
- Use Button 1 to cycle through tests

### Android App Usage

Login/Registration:
1. Open app
2. For new users: Tap "Register"
   - Enter email, password, name
   - Verify email
3. For existing users: Enter credentials and login
4. Use "Remember Me" for auto-login

Dashboard:
1. Select device from dropdown (if multiple devices)
2. View real-time temperature and humidity gauges
3. Monitor device online/offline status
4. Check current setpoint and SSR status
5. Use START/STOP buttons to control drying
6. Adjust setpoint remotely with slider

Charts:
1. Navigate to Charts tab
2. Select data type (Temperature/Humidity/Combined)
3. Choose time range (24h/7d/30d/Custom)
4. Interact with chart (zoom, pan, tap for details)
5. View statistics (min/max/average)
6. Export data to CSV
7. Share charts via email or storage

Device Management:
1. Navigate to Devices tab
2. View all paired devices
3. Tap device to see details
4. Swipe left to delete device
5. Tap edit icon to rename device
6. Use floating action button to add new device

Profile:
1. Navigate to Profile tab
2. View and edit user profile
3. Change password
4. Configure notification preferences
5. Set temperature unit (Celsius/Fahrenheit)
6. Adjust data refresh interval
7. View app version and information
8. Logout

## Code Structure

### ESP32 Main Components

RiceDryer.ino:
- Main Arduino sketch
- Initialization and setup
- Main control loop
- Integration of all modules

FirebaseConfig:
- Credential management
- Firebase connection parameters
- Modular design for security
- Methods: getFirebaseHost(), getFirebaseAuth(), getDatabaseURL(), getProjectId()

WiFiManagerCustom:
- WiFi connection management
- Captive portal configuration
- Auto-reconnection logic
- Status monitoring
- Methods: begin(), isConnected(), reconnect(), reset()

Button:
- Debouncing algorithm
- Short press and long press detection
- State management
- Methods: isPressed(), isLongPressed(), update()

DHT22Sensor:
- Temperature and humidity reading
- Error handling
- Data validation
- Methods: readTemperature(), readHumidity(), isValid()

SSR:
- Solid State Relay control
- ON/OFF state management
- Safety checks
- Methods: turnOn(), turnOff(), isOn()

LCDDisplay:
- 16x2 LCD management
- Multiple display modes
- Update scheduling
- Methods: showTemperature(), showStatus(), showPairingCode()

PinConfig.h:
- Centralized pin definitions
- Hardware configuration constants

### Android Main Components

Models (data/model/):
- User.java: User profile data structure
- Device.java: Device information and status
- SensorReading.java: Sensor data with timestamp
- Command.java: Remote control commands

Remote (data/remote/):
- FirebaseAuthManager.java: Firebase Authentication wrapper (singleton)
- FirebaseDataSource.java: Firebase Database reference manager

Repositories (data/repository/):
- AuthRepository.java: Authentication operations (login, register, password reset)
- DeviceRepository.java: Device management (pairing, listing, real-time listening)

Utilities (utils/):
- Constants.java: App-wide constants (Firebase paths, preferences keys)
- DateUtils.java: Date formatting and time-ago calculations
- ValidationUtils.java: Input validation (email, password, pairing code)

UI - Auth (ui/auth/):
- LoginActivity.java: Login screen implementation
- AuthViewModel.java: Authentication ViewModel with LiveData

### Design Patterns

ESP32:
- Modular Design: Separate files for each hardware component
- Singleton Pattern: Firebase and WiFi managers
- State Machine: Display modes and operation states

Android:
- MVVM Architecture: Model-View-ViewModel separation
- Repository Pattern: Data access abstraction
- LiveData: Reactive data observation
- ViewBinding: Type-safe view access
- Singleton: Firebase managers

### ESP32 Code Flow

#### Compilation Flow Diagram

```
RiceDryer.ino (Line 28: //#define DEVELOPMENT_MODE)
        │
        ├─────── Uncommented ──────┐
        │                          │
        ▼                          ▼
DEVELOPMENT_MODE          PRODUCTION_MODE
        │                          │
        ▼                          ▼
Include Only:            Include All:
• Button.h              • WiFi.h
• DHT22Sensor.h         • Firebase_ESP_Client.h
• SSR.h                 • WiFiManagerCustom.h
• LCDDisplay.h          • FirebaseConfig.h
• PinConfig.h           • All component headers
        │                          │
        ▼                          ▼
Components:              Components:
• devDHT                • dht, relay1, relay2
• devHeater, devBlower  • button1, button2, button3
• devLCD                • lcd, tempController
                        • Firebase objects
        │                          │
        ▼                          ▼
Functions:               Functions:
• runDevelopmentMode()  • productionSetup()
• handleSerial...()     • productionLoop()
                        • 50+ functions
        │                          │
        └──────────┬───────────────┘
                   ▼
            setup() dispatcher
                   │
        ┌──────────┴──────────┐
        ▼                     ▼
   DEVELOPMENT           PRODUCTION
   runDevelopment()      productionSetup()
   (infinite loop)            │
                             ▼
                        loop() calls
                        productionLoop()
```

#### Production Mode Execution Flow

```
ESP32 Boot
    │
    ▼
productionSetup()
    │
    ├─ Initialize Hardware (buttons, relays, LCD, DHT22, PID)
    ├─ Check Button 1 at Startup (test mode if pressed)
    ├─ Initialize WiFi (captive portal if needed)
    ├─ Initialize NTP (Philippines UTC+8)
    ├─ Initialize Firebase
    ├─ Register Device
    └─ Check Pairing Status
    │
    ▼
productionLoop() (infinite)
    │
    ├─ Check WiFi Status (reconnect if needed)
    ├─ If Not Paired:
    │   ├─ Display pairing code
    │   ├─ Check for pairing
    │   └─ Return (skip rest)
    ├─ Handle Buttons:
    │   ├─ Button 1: Mode toggle
    │   ├─ Button 2: Start/Stop or Increase
    │   └─ Button 3: Reset or Decrease
    ├─ Setpoint Adjustment (if in setting mode)
    ├─ Read Sensors (DHT22 every 2s)
    ├─ Control Drying:
    │   ├─ PID temperature control
    │   ├─ Check humidity target
    │   ├─ Control relays
    │   └─ Auto-stop logic
    ├─ Firebase Communication:
    │   ├─ Update current status (5s interval)
    │   ├─ Log historical data (30s interval)
    │   └─ Check remote commands (1s interval)
    └─ Update LCD Display
    │
    └─ Loop back
```

#### Development Mode Execution Flow

```
ESP32 Boot
    │
    ▼
setup() → runDevelopmentMode()
    │
    ├─ Initialize Hardware (DHT22, relays, LCD)
    ├─ Display on LCD:
    │   "DEVELOPMENT MODE"
    │   "Hardware Test"
    │   "Open Serial @115200"
    │   "Type HELP"
    └─ Print startup message to Serial
    │
    ▼
Infinite Loop
    │
    ├─ Read Serial Input
    ├─ Parse Command:
    │   • LCD_TEST, LCD_CLEAR, LCD_PRINT
    │   • DHT_READ
    │   • RELAY_HEATER_ON/OFF
    │   • RELAY_BLOWER_ON/OFF
    │   • STATUS, HELP
    ├─ Execute Action:
    │   • Update LCD
    │   • Read sensor
    │   • Control relays
    │   • Print status
    └─ delay(50ms)
    │
    └─ Loop back
```

#### File Structure

```
RiceDryer.ino (1215 lines)
│
├── [Lines 1-28]     Mode configuration header
│                    📋 EDIT HERE TO SWITCH MODES
│
├── [Lines 30-47]    Conditional includes
│                    📚 WiFi/Firebase only if PRODUCTION
│
├── [Lines 49-781]   Production mode variables & functions
│                    🚀 PRODUCTION ONLY
│                    (Firebase, WiFi, PID, etc.)
│
├── [Lines 783-920]  Development mode code
│                    🔧 DEVELOPMENT ONLY
│                    (Serial commands, testing)
│
├── [Lines 922-1184] Production mode functions
│                    🚀 productionSetup/Loop wrappers
│
└── [Lines 1186-1215] Main entry points
                      🎯 MODE DISPATCHER
                      setup() and loop()
```

## Version History

### Version 1.0.0 (December 12, 2025) - Current

**ESP32 Firmware: 100% Complete ✅**

Major Features:
- Full WiFi Manager integration with captive portal
- Firebase Realtime Database synchronization
- NTP time synchronization (Philippines UTC+8)
- 3-button interface with multiple modes
- Dual relay system (heater + fan)
- PID temperature control
- Auto-stop at humidity target
- Device pairing with 6-digit code
- Real-time data streaming (5s interval)
- Historical data logging (30s interval)
- Remote command execution
- Development Mode for hardware testing

Code Optimizations Applied:
- Removed OTA update functionality (~30-50KB saved)
- Removed Serial debug output (~10-15KB saved)
- Removed test mode functions (~5-8KB saved)
- Total savings: ~50-80KB
- Current size: ~420KB (13% of 3MB, 32% of 1.3MB)

**Android Application: 98% Complete ✅**

Completed Features:
- Full authentication system (login, register, password reset)
- Multi-device support and management
- Real-time dashboard with animated gauges
- Interactive charts with time range filters
- Device pairing with code validation
- Real-time Firebase listeners
- Local caching with Room database
- Material Design 3 UI
- Dark theme support

**Hardware Configuration:**
- ESP32 38-pin development board
- DHT22 temperature/humidity sensor
- 20x4 I2C LCD display
- Dual SSR control (low trigger)
- 3-button interface
- 12V power system with solar option

**Last Updated:** December 12, 2025

### Version 0.9.0 (November 14, 2025)

**NTP Time Synchronization Update:**
- Added NTP initialization with Philippines timezone (UTC+8)
- Implemented `getTimestamp()` function for Unix timestamps
- Updated all Firebase writes to use real timestamps
- Changed pairing code expiry to use Unix timestamps
- Updated Android app to handle Unix timestamps
- Fixed time filtering in charts
- Re-enabled pairing code expiry validation

**Database Structure Changes:**
- `lastUpdate`: Now uses Unix timestamp in milliseconds
- History keys: Unix timestamp in seconds
- History data: Includes timestamp field in milliseconds
- Pairing: Added `generatedAt` and `expiresAt` fields

### Version 0.8.0 (December 7, 2025)

**Mode Implementation:**
- Added compile-time mode switching
- Implemented DEVELOPMENT_MODE for hardware testing
- Created productionSetup() and productionLoop() wrappers
- Added serial command interface for testing
- Separated production and development components

**Development Mode Commands:**
- LCD testing and control
- DHT22 sensor reading
- Individual relay control (heater/blower)
- Status monitoring
- Help system

### Version 0.7.0 (December 2, 2025)

**Code Size Optimization:**
- Removed ArduinoOTA library
- Removed test mode functions
- Removed Serial debug statements
- Optimized WiFiManager strings
- Optimized TemperatureController output
- Reduced sketch size by 50-80KB

**Documentation:**
- Created OPTIMIZATION_GUIDE.md
- Created CHANGE_PARTITION_SCHEME.md
- Created ARDUINO_IDE2_PARTITION_FIX.md
- Added detailed compilation instructions

### Version 0.6.0 (November 2025)

**Initial Release:**
- WiFiManager integration
- Firebase Realtime Database connection
- Basic device registration
- Pairing code system
- Real-time data streaming
- Historical data logging
- Remote command execution
- LCD display implementation
- DHT22 sensor integration
- SSR relay control
- Button interface

**Known Limitations:**
- Used millis() for timestamps (fixed in v0.9.0)
- Test mode required manual entry
- No development mode separation
- No OTA updates (later removed for size)

## Firebase Database Structure

```json
{
  "users": {
    "{userId}": {
      "email": "user@example.com",
      "name": "John Doe",
      "createdAt": 1234567890,
      "devices": {
        "{deviceId}": {
          "deviceName": "Kitchen Dryer",
          "pairedAt": 1234567890,
          "notifications": true
        }
      }
    }
  },
  "devices": {
    "{deviceId}": {
      "deviceInfo": {
        "macAddress": "AA:BB:CC:DD:EE:FF",
        "firmwareVersion": "1.0.0",
        "hardwareVersion": "1.0",
        "pairedTo": "{userId}",
        "deviceName": "Kitchen Dryer"
      },
      "current": {
        "temperature": 45.5,
        "humidity": 65.2,
        "setpoint": 50.0,
        "ssrStatus": true,
        "dryingActive": true,
        "online": true,
        "lastUpdate": 1234567890
      },
      "history": {
        "{timestamp}": {
          "temperature": 45.5,
          "humidity": 65.2,
          "setpoint": 50.0,
          "ssrStatus": true
        }
      },
      "commands": {
        "action": "START",
        "value": 50,
        "timestamp": 1234567890,
        "acknowledged": false
      },
      "alerts": {
        "tempHigh": 60,
        "tempLow": 30,
        "humidityHigh": 80,
        "humidityLow": 40
      }
    }
  },
  "devicePairing": {
    "{pairingCode}": {
      "deviceId": "{deviceId}",
      "expiresAt": 1234567890,
      "used": false
    }
  }
}
```

## Implementation Progress

### Completed Work (60% Overall)

#### ESP32 Firmware (100% Complete)

WiFiManager Integration:
- Added WiFiManager library for easy WiFi configuration
- Captive portal setup with SSID "RiceDryer_Setup"
- Automatic WiFi reconnection with status monitoring
- LCD displays WiFi connection status
- 3-minute timeout for configuration portal

Firebase Realtime Database Integration:
- Firebase ESP32 Client library integrated
- Connection to Firebase RTDB
- Device registration with unique ID (MAC address based)
- Automatic device info storage (firmware version, hardware version)
- Connection error handling and retry mechanism

Real-time Data Streaming:
- Sends data every 5 seconds to Firebase
- Path: /devices/{deviceId}/current/
- Data includes: temperature, humidity, setpoint, SSR status, drying state, online status, timestamp

Historical Data Logging:
- Logs sensor readings every 30 seconds
- Path: /devices/{deviceId}/history/{timestamp}/
- Includes temperature, humidity, setpoint, SSR state

Remote Control Capability:
- Listens to Firebase commands every 1 second
- Path: /devices/{deviceId}/commands/
- Supported commands: START, STOP, SET_TEMP
- Command acknowledgment sent back to Firebase

Device Pairing Mechanism:
- Generates random 6-digit pairing code on first boot
- Code displayed on LCD for 10 minutes
- Code stored in Firebase with expiration
- Device associates with user account after successful pairing

OTA Updates Support:
- ArduinoOTA library integrated
- Hostname: "RiceDryer"
- Ready for over-the-air firmware updates

#### Android App (40% Complete)

Project Structure and Dependencies:
- Firebase BOM 32.7.0 (Auth, Database, Messaging, Analytics, Crashlytics)
- Navigation Component 2.7.6
- Lifecycle Components 2.7.0
- Room Database 2.6.1
- Material Design 3 1.11.0
- MPAndroidChart v3.1.0
- Lottie 6.3.0
- ViewBinding and DataBinding enabled

Data Models Created:
- User.java: User profile data
- Device.java: Device information and status
- SensorReading.java: Real-time sensor data
- Command.java: Remote control commands

Firebase Integration Layer:
- FirebaseAuthManager.java: Authentication management
- FirebaseDataSource.java: Database reference management
- Singleton pattern for efficient resource usage

Repository Pattern:
- AuthRepository.java: Login, register, password reset, user profile creation
- DeviceRepository.java: Device loading, pairing, real-time listening, command sending

Utility Classes:
- Constants.java: App-wide constants
- DateUtils.java: Date formatting and time-ago calculations
- ValidationUtils.java: Input validation (email, password, pairing code)

UI Resources:
- colors.xml: 25+ colors (primary teal/green, secondary orange, status colors, gauge colors)
- strings.xml: 60+ string resources
- Material Design 3 theming

Authentication System:
- AuthViewModel.java: ViewModel for auth operations
- LoginActivity.java: Complete login implementation with validation and error handling
- activity_login.xml: Professional Material Design login UI

Security Implementation:
- Modular FirebaseConfig for ESP32
- WiFiManagerCustom wrapper
- Multi-layer .gitignore protection
- Template files for safe sharing

### Remaining Work (40%)

High Priority Core Features:
- Android: Register Activity
- Android: Forgot Password Activity
- Android: Splash Screen
- Android: Main Dashboard with bottom navigation
- Android: Dashboard Fragment with real-time gauges
- Android: Devices Fragment with device list and pairing
- Android: Charts Fragment with MPAndroidChart
- Android: Profile Fragment with settings
- Firebase: Database Security Rules

Medium Priority Enhanced Features:
- Android: Custom Gauge Views
- Android: Device Status Service
- Android: Push Notifications with FCM
- Android: Room Database for offline support
- Android: Onboarding Flow
- ESP32: Data Retention (automatic cleanup)

Low Priority Polish and Testing:
- Android: Loading States (shimmer effects)
- Android: Dark Theme
- Android: Animations and transitions
- Testing: Unit Tests (70% coverage target)
- Testing: UI Tests
- Documentation: User Manual
- Testing: End-to-End system testing

## Implementation Plan

### Tech Stack

ESP32: Arduino C++, WiFiManager, Firebase ESP32, OTA Updates
Android: Java, MVVM Architecture, Firebase (Auth, Database, Analytics, Crashlytics), Material Design 3
Backend: Firebase Realtime Database, Cloud Messaging
Libraries: MPAndroidChart, Lottie, Room, Navigation Component, ViewBinding

### Phase 1: ESP32 Core Functionality (COMPLETED)

Task 1.1: WiFiManager Integration
- Install WiFiManager library via Arduino Library Manager
- Add WiFiManager initialization in setup()
- Configure captive portal with custom SSID "RiceDryer_Setup"
- Test WiFi configuration flow
- Add WiFi status to LCD display

Task 1.2: Firebase ESP32 Setup
- Install Firebase ESP32 library
- Configure Firebase credentials from google-services.json
- Implement device registration with MAC address
- Create unique device ID
- Test connection to Firebase

Task 1.3: Real-time Data Streaming
- Create sendDataToFirebase() function
- Update Firebase every 5 seconds with current readings
- Implement connection error handling
- Add retry mechanism with exponential backoff

Task 1.4: Remote Command Listener
- Create listenForCommands() function
- Parse JSON commands from Firebase
- Implement command handlers (START, STOP, SET_TEMP)
- Add command acknowledgment

Task 1.5: Device Pairing System
- Generate random 6-digit pairing code
- Store code in Firebase with expiration
- Display code on LCD for 10 minutes
- Implement pairing verification

### Phase 2: Android Project Setup (COMPLETED)

Task 2.1: Project Configuration
- Update build.gradle with all dependencies
- Enable ViewBinding and DataBinding
- Setup Navigation Component
- Configure Firebase SDK

Task 2.2: Theme and Resources
- Create Material Design 3 theme
- Define colors, styles, dimensions
- Add string resources
- Import Lottie animations

Task 2.3: Database Layer
- Create Room database entities
- Define DAOs
- Setup database migrations
- Create repository pattern base classes

### Phase 3: Authentication System (PARTIALLY COMPLETE)

Task 3.1: Splash Screen (Pending)
- Design splash layout with Lottie animation
- Check authentication state
- Navigate to Login or Dashboard

Task 3.2: Login Activity (COMPLETED)
- Design login UI with Material components
- Implement LoginViewModel
- Connect to Firebase Auth
- Add input validation
- Handle login errors

Task 3.3: Register Activity (Pending)
- Design registration form
- Implement registration logic
- Add email verification flow
- Validate password strength

Task 3.4: Forgot Password (Pending)
- Create forgot password UI
- Implement password reset email
- Handle success/error states

### Phase 4: Main Dashboard (Pending)

Task 4.1: Bottom Navigation
- Setup Navigation Component
- Create 4 fragments (Home, Charts, Devices, Profile)
- Implement navigation logic
- Add navigation animations

Task 4.2: Dashboard Fragment UI
- Design dashboard layout
- Add device selector spinner
- Create gauge placeholders
- Add control buttons
- Implement status indicators

Task 4.3: Custom Gauge Views
- Create custom GaugeView class
- Implement animated needle
- Add color zones (green/yellow/red)
- Connect to ViewModel LiveData

Task 4.4: Real-time Data Binding
- Setup Firebase listeners in ViewModel
- Update UI with LiveData
- Implement auto-refresh
- Handle connection state changes

Task 4.5: Remote Control
- Implement Start/Stop button logic
- Add setpoint adjustment slider
- Create command sender
- Show command feedback

### Phase 5: Device Management (Pending)

Task 5.1: Device Pairing
- Create pairing dialog with code input
- Validate code against Firebase
- Associate device with user
- Add success animation

Task 5.2: Devices List
- Create RecyclerView adapter
- Load devices from Firebase
- Show device status cards
- Implement swipe-to-delete
- Add device renaming

Task 5.3: Device Status Monitoring
- Create background service
- Monitor online/offline status
- Send notifications on status change
- Update UI indicators

### Phase 6: Charts and Analytics (Pending)

Task 6.1: Charts UI
- Create tabbed layout
- Setup MPAndroidChart
- Add date range picker
- Design chart settings

Task 6.2: Data Loading
- Fetch historical data from Firebase
- Parse and format for charts
- Cache in Room database
- Implement pagination

Task 6.3: Chart Rendering
- Configure line chart appearance
- Add zoom and pan gestures
- Display statistics (min/max/avg)
- Implement chart animations

Task 6.4: CSV Export
- Create CSV formatter
- Add date range selector
- Implement FileProvider
- Add share intent

### Phase 7: Notifications and Polish (Pending)

Task 7.1: Push Notifications
- Setup Firebase Cloud Messaging
- Create notification service
- Define notification channels
- Implement alert logic

Task 7.2: Profile and Settings
- Design settings UI
- Implement preference storage
- Add account management
- Create about screen

Task 7.3: Error Handling
- Add loading states
- Design error layouts
- Implement retry logic
- Add timeout handling

Task 7.4: UI/UX Polish
- Add animations and transitions
- Implement empty states
- Create onboarding flow
- Add tooltips and hints

### Phase 8: Testing and Deployment (Pending)

Task 8.1: Unit Tests
- Test ViewModels
- Test repositories
- Test utilities
- Achieve 70% coverage

Task 8.2: Integration Tests
- Test Firebase integration
- Test authentication flow
- Test data synchronization

Task 8.3: End-to-End Testing
- Test complete user flows
- Test offline scenarios
- Performance testing
- Memory leak detection

Task 8.4: Documentation
- Create user manual
- Write developer documentation
- Add code comments
- Create setup guide

Task 8.5: Release Preparation
- Generate signed APK
- Create Play Store listing
- Prepare screenshots
- Write release notes

### Timeline

- Total Duration: 6 weeks
- Phase 1-2: COMPLETED
- Phase 3: Partially complete (1 week remaining)
- Phase 4-5: 2 weeks
- Phase 6-7: 2 weeks
- Phase 8: 1 week

## Testing

### ESP32 Testing

Test Mode:
1. Hold button during power-on
2. ESP32 enters test mode
3. Press button to cycle through tests:
   - DHT22 Sensor reading
   - SSR activation (heater on/off)
   - LCD Display modes

Manual Testing Checklist:
- [ ] WiFi configuration via captive portal works
- [ ] ESP32 connects to Firebase successfully
- [ ] LCD shows pairing code on first boot
- [ ] Temperature readings are accurate (±0.5°C)
- [ ] Humidity readings are accurate (±2%)
- [ ] SSR turns heater on/off based on setpoint
- [ ] Real-time data updates in Firebase every 5 seconds
- [ ] Historical data logs every 30 seconds
- [ ] Remote commands (START/STOP/SET_TEMP) work
- [ ] Device pairing completes successfully
- [ ] OTA updates can be initiated

### Android Testing

Unit Testing:
- ViewModels: Test business logic and LiveData updates
- Repositories: Test Firebase interactions and data transformations
- Utilities: Test validation, date formatting, constants

UI Testing:
- Login flow: Email validation, password validation, error handling
- Registration flow: Complete user registration
- Device pairing: Code validation, Firebase association
- Dashboard: Real-time data display, gauge updates
- Charts: Data loading, chart rendering, CSV export

Integration Testing:
- Firebase Authentication: Login, register, password reset
- Firebase Database: Read/write operations, real-time listeners
- Device pairing: End-to-end pairing process
- Data synchronization: ESP32 to Android real-time updates

End-to-End Testing:
- [ ] User can register and login
- [ ] User can pair ESP32 device
- [ ] Real-time data updates every 5 seconds
- [ ] Temperature and humidity gauges animate correctly
- [ ] Start/Stop commands control ESP32
- [ ] Setpoint adjustment is reflected on ESP32
- [ ] Charts display historical data correctly
- [ ] CSV export works
- [ ] Notifications arrive on device events
- [ ] Offline mode works (cached data)
- [ ] Multiple devices can be managed
- [ ] Password reset email is received
- [ ] App handles network errors gracefully

Performance Testing:
- App startup time: < 2 seconds
- Data loading time: < 1 second
- Chart rendering: < 500ms
- Memory usage: < 100MB
- Battery consumption: Minimal background usage

## Troubleshooting

### Compilation Issues

#### "Sketch too big" Error

**Problem:** `Sketch too big; text section exceeds available space in board`

**Root Cause:** 
- Default partition scheme allocates only 1.3MB for app
- Firebase + WiFiManager requires ~420KB
- This exceeds the default limit

**Solution 1: Change Partition Scheme (Arduino IDE 1.x)**
1. Go to Tools → Partition Scheme
2. Select "Minimal SPIFFS (1.9MB APP)" or "Huge APP (3MB No OTA)"
3. Recompile and upload

**Solution 2: Arduino IDE 2.x (No Partition Menu)**

If "Partition Scheme" option is not visible in Tools menu:

**Method A - Edit boards.txt:**
1. Navigate to:
   ```
   C:\Users\<YourUsername>\AppData\Local\Arduino15\packages\esp32\hardware\esp32\<version>\boards.txt
   ```
2. Find your board section: `esp32.name=ESP32 Dev Module`
3. Locate line: `esp32.build.partitions=default`
4. Change to: `esp32.build.partitions=huge_app`
5. Save file and restart Arduino IDE

**Method B - Create platform.local.txt:**
1. Navigate to:
   ```
   C:\Users\<YourUsername>\AppData\Local\Arduino15\packages\esp32\hardware\esp32\<version>\
   ```
2. Create new file: `platform.local.txt`
3. Add this line: `build.partitions=huge_app`
4. Save and restart Arduino IDE

**Method C - Update ESP32 Board Package:**
1. Tools → Board → Boards Manager
2. Search "esp32"
3. Update to version 2.0.0 or newer
4. Restart Arduino IDE
5. Check if partition scheme option now appears

**Partition Options Explained:**
```
Default (1.3MB APP)         ❌ TOO SMALL
├─ Bootloader
├─ App: 1.3MB
└─ SPIFFS: 1.5MB

Minimal SPIFFS (1.9MB APP)  ✅ RECOMMENDED
├─ Bootloader
├─ App: 1.9MB
└─ SPIFFS: 190KB

Huge APP (3MB No OTA)       ✅ BEST
├─ Bootloader
├─ App: 3MB
└─ SPIFFS: 1MB

No OTA (2MB APP)            ✅ GOOD
├─ Bootloader
├─ App: 2MB
└─ SPIFFS: 2MB
```

**Expected Result After Fix:**
```
Before (1.3MB partition):
Sketch uses 1250000 bytes (95%) ❌ TOO CLOSE

After (3MB partition):
Sketch uses 1250000 bytes (38%) ✅ PLENTY OF ROOM
```

**Verification:**
Add this to setup() temporarily to check current partition:
```cpp
Serial.begin(115200);
Serial.print("Sketch size: ");
Serial.println(ESP.getSketchSize());
Serial.print("Free sketch space: ");
Serial.println(ESP.getFreeSketchSpace());
```

#### Library Installation Issues

**Problem:** `Firebase_ESP_Client.h: No such file or directory`

**Solution:**
1. Open Arduino IDE
2. Sketch → Include Library → Manage Libraries
3. Search "Firebase ESP32 Client"
4. Install "Firebase Arduino Client Library for ESP8266 and ESP32" by Mobizt
5. Verify version 4.4.14 or higher
6. Restart Arduino IDE

**Problem:** Multiple library versions causing conflicts

**Solution:**
1. Close Arduino IDE
2. Navigate to Arduino libraries folder:
   - Windows: `Documents\Arduino\libraries\`
3. Delete conflicting library folders
4. Reinstall latest version via Library Manager
5. Restart Arduino IDE

### ESP32 Issues

WiFi Connection Fails:
- Check WiFi credentials in captive portal
- Verify WiFi router is 2.4GHz (ESP32 doesn't support 5GHz)
- Check signal strength (ESP32 should be within range)
- Try holding button + reset to enter setup mode again
- Power cycle the device

Firebase Connection Fails:
- Verify WiFi is connected first (check LCD status)
- Check FirebaseConfig.cpp has correct credentials
- Verify Firebase Database URL is correct
- Check internet connection is working
- Review Firebase Database Rules
- Check Firebase project is active

Sensor Readings Incorrect:
- Verify DHT22 wiring (VCC to 3.3V, GND to GND, DATA to GPIO 14)
- Check for loose connections
- Try different DHT22 sensor (sensor may be faulty)
- Verify pull-up resistor (4.7K-10K ohm) on DATA line
- Allow 2-second stabilization time after power-on

SSR Not Working:
- Check SSR wiring (control pin to GPIO 27)
- Verify SSR power supply (3-32V DC on control side)
- Test SSR with multimeter
- Check load connection (24-380V AC)
- Verify setpoint is set correctly
- Check if heater is below setpoint

LCD Not Displaying:
- Check I2C wiring (SDA to GPIO 21, SCL to GPIO 22)
- Verify LCD address (0x27 or 0x3F) in code
- Verify 5V power supply to LCD
- Try I2C scanner sketch to detect address

Pairing Code Not Showing:
- Device may already be paired (check Firebase)
- Reset device to generate new code
- Check LCD is working
- Verify Firebase connection is active
- Wait up to 30 seconds after boot

### Android Issues

App Crashes on Start:
- Verify google-services.json is in correct location (app/ folder)
- Check package name matches (com.qppd.ricedryer)
- Ensure Gradle sync completed successfully
- Clear cache: Build > Clean Project > Rebuild Project
- Check Firebase project is configured correctly

Cannot Connect to Firebase:
- Verify internet connection
- Check google-services.json is not corrupted
- Verify Firebase Database URL in Firebase Console
- Check Firebase Authentication is enabled
- Review Firebase Database Rules

Device Pairing Fails:
- Verify ESP32 is showing pairing code on LCD
- Check code hasn't expired (10 minute limit)
- Ensure code is entered correctly (6 digits)
- Verify Firebase connection on both ESP32 and Android
- Check internet on both devices
- Try generating new code (reset ESP32)

Real-time Data Not Updating:
- Check device is online (status indicator)
- Verify ESP32 has internet connection
- Check Firebase listeners are active
- Try force-closing and reopening app
- Verify Firebase Database path is correct
- Check data refresh interval in settings

Charts Not Loading:
- Verify historical data exists in Firebase
- Check date range selection
- Try different time range
- Check internet connection
- Clear app cache
- Verify Room database is working

Notifications Not Arriving:
- Check notification permissions are granted
- Verify FCM is configured in Firebase
- Check notification settings in app
- Ensure device has internet connection
- Check Firebase Cloud Messaging is enabled
- Review notification channel settings

Login/Registration Issues:
- Verify email format is correct
- Check password meets requirements (min 6 characters)
- Ensure Firebase Authentication is enabled
- Check internet connection
- Verify email doesn't already exist (for registration)
- Try password reset if password forgotten

### General Issues

Slow Response Time:
- Check internet connection speed
- Verify Firebase Database is in nearest region
- Reduce data refresh frequency
- Check for memory leaks
- Optimize Firebase queries
- Consider implementing data pagination

High Battery Consumption:
- Reduce data refresh frequency
- Implement proper background service management
- Use Firebase listeners efficiently
- Optimize wake locks
- Check for infinite loops or excessive polling

Data Mismatch ESP32 vs Android:
- Check system time on both devices
- Verify timezone settings
- Check data refresh intervals
- Ensure Firebase paths are correct
- Review data transformation logic
- Check for caching issues

## Development Roadmap

### Version 1.0 (Current Development)

Core Features:
- ESP32 firmware with WiFiManager and Firebase
- Android app with authentication
- Real-time monitoring
- Device pairing
- Basic controls

Status: 60% complete
Target: 3 weeks

### Version 1.1 (Next Release)

Enhanced Features:
- Push notifications
- Offline mode with Room database
- Advanced charts with multiple time ranges
- CSV data export
- Dark theme
- Multiple device support

Status: Planned
Target: 2 weeks after v1.0

### Version 1.2

Advanced Features:
- Voice control integration
- Automated drying programs
- Weather-based optimization
- Cloud-based analytics
- Machine learning for optimal drying
- Multi-language support

Status: Planned
Target: Q1 2026

### Version 2.0

Professional Features:
- Web dashboard
- Commercial fleet management
- Advanced analytics and reporting
- Predictive maintenance
- Integration with agricultural systems
- API for third-party integrations

Status: Concept
Target: Q2 2026

### Continuous Improvements

Security:
- Regular security audits
- Credential rotation
- Enhanced encryption
- Penetration testing

Performance:
- Code optimization
- Database query optimization
- Battery usage optimization
- Network efficiency

User Experience:
- User feedback implementation
- A/B testing
- Accessibility improvements
- Performance monitoring

## Technical Specifications

### ESP32 Specifications

Microcontroller:
- Chip: ESP32-WROOM-32
- CPU: Xtensa dual-core 32-bit LX6
- Clock Frequency: 240 MHz
- SRAM: 520 KB
- Flash: 4 MB
- GPIO Pins: 34

Connectivity:
- WiFi: 802.11 b/g/n
- Frequency: 2.4 GHz
- Range: Up to 100 meters (open space)
- Security: WPA/WPA2

Power:
- Input Voltage: 5V via USB or external
- Operating Voltage: 3.3V
- Deep Sleep Current: 10 µA
- Active Current: 80-240 mA
- Solar Panel: 12V/10W (optional)

Environmental:
- Operating Temperature: -40°C to 85°C
- Storage Temperature: -40°C to 125°C
- Humidity: 0% to 95% RH (non-condensing)

### Android Specifications

Minimum Requirements:
- Android Version: 7.0 (Nougat) - API Level 24
- RAM: 2 GB
- Storage: 50 MB free space
- Screen: 5 inches minimum
- Internet: WiFi or mobile data

Recommended:
- Android Version: 10.0 or higher
- RAM: 4 GB or more
- Storage: 100 MB free space
- Screen: 6 inches or larger
- Internet: Stable WiFi or 4G/5G

Supported Features:
- Push Notifications (Android 8.0+)
- Background Services
- Biometric Authentication (Android 9.0+)
- Dark Theme (Android 10.0+)

### Network Requirements

ESP32:
- WiFi: 2.4GHz 802.11 b/g/n
- Bandwidth: Minimum 128 kbps
- Latency: < 500ms
- Data Usage: ~1 MB per day

Android:
- Connection: WiFi or mobile data
- Bandwidth: Minimum 256 kbps
- Latency: < 1000ms
- Data Usage: ~5 MB per day

Firebase:
- Realtime Database: Up to 100 simultaneous connections (free tier)
- Data Transfer: 10 GB/month download, 1 GB/month upload (free tier)
- Storage: 1 GB (free tier)

### Sensor Specifications

DHT22:
- Temperature Range: -40°C to 80°C
- Temperature Accuracy: ±0.5°C
- Humidity Range: 0-100% RH
- Humidity Accuracy: ±2-5% RH
- Response Time: 2 seconds
- Power: 3.3-5V, max 2.5mA

### Control Specifications

SSR (Solid State Relay):
- Control Voltage: 3-32V DC
- Control Current: 5-25 mA
- Load Voltage: 24-380V AC
- Load Current: 25A continuous
- Switching Time: 10ms
- Zero-crossing: Yes

Heater:
- Power: Up to 2000W (at 220V AC)
- Voltage: 220V AC / 110V AC
- Control: On/Off via SSR

### Performance Metrics

Real-time Updates:
- ESP32 to Firebase: 5 seconds
- Firebase to Android: < 1 second
- Total latency: < 6 seconds

Historical Logging:
- Interval: 30 seconds
- Retention: 7 days (configurable)
- Storage per day: ~2,880 records

Command Response:
- Android to Firebase: < 1 second
- Firebase to ESP32: < 2 seconds
- Total response time: < 3 seconds

Battery Life (with solar):
- Continuous operation: Indefinite
- Without solar: ~24 hours (2500mAh battery)
- Deep sleep mode: ~7 days

## Contributing

We welcome contributions to the Rice Dryer project. Please follow these guidelines:

### How to Contribute

1. Fork the repository
2. Create a feature branch (git checkout -b feature/YourFeature)
3. Setup credentials using template files
4. Make your changes
5. Test thoroughly
6. Commit your changes (git commit -m 'Add YourFeature')
7. Push to the branch (git push origin feature/YourFeature)
8. Open a Pull Request

### Code Standards

ESP32 (Arduino C++):
- Follow Arduino style guide
- Use meaningful variable names
- Comment complex logic
- Keep functions small and focused
- Test on actual hardware

Android (Java):
- Follow Google Java Style Guide
- Use MVVM architecture pattern
- Implement proper error handling
- Write unit tests for ViewModels and Repositories
- Use ViewBinding for view access

General:
- Write clear commit messages
- Update documentation
- Never commit credentials
- Verify .gitignore protection before committing

### Testing Requirements

Before submitting PR:
- [ ] Code compiles without errors
- [ ] All existing tests pass
- [ ] New tests added for new features
- [ ] Manual testing completed
- [ ] Documentation updated
- [ ] No credentials in committed code

### Reporting Issues

When reporting issues, include:
- Device information (ESP32 board, Android version)
- Steps to reproduce
- Expected vs actual behavior
- Error messages or logs
- Screenshots if applicable

### Feature Requests

For new features:
- Describe the feature clearly
- Explain use case and benefits
- Consider implementation complexity
- Discuss potential alternatives

## Android Application

### Technology Stack

- **Language:** Kotlin 2.0.21
- **UI Framework:** Jetpack Compose with Material Design 3
- **Architecture:** MVVM (Model-View-ViewModel)
- **Dependency Injection:** Manual factory pattern
- **Database:** Room 2.6.1 for local caching
- **Networking:** Firebase SDK (Auth, Realtime Database)
- **Charts:** MPAndroidChart v3.1.0
- **Async:** Kotlin Coroutines and Flow
- **Navigation:** Jetpack Navigation Compose 2.8.0

### Key Components

#### Authentication (AuthViewModel, AuthRepository)
- Email/password registration with validation
- Login with remember me functionality
- Password reset via email
- Session management with FirebaseAuth

#### Device Management (DeviceListViewModel, DeviceRepository)
- Real-time device list with status indicators
- Device pairing with 6-digit code validation
- Connection status monitoring
- Last update tracking

#### Dashboard (DashboardViewModel)
- Animated circular gauges for temperature/humidity
- Real-time data updates via Firebase listeners
- START/STOP command controls
- Setpoint adjustments with sliders
- Heater/Fan status indicators

#### Charts & Analytics (ChartsViewModel)
- Temperature and humidity line charts
- Time range filters (1h, 6h, 24h, 1 week)
- Statistics cards (min, max, average)
- Zoom and pan interactions
- Historical data visualization

#### Data Models
- **DeviceData:** Complete device state (info, status, settings, commands)
- **DeviceStatus:** Real-time sensor readings and relay states
- **DeviceInfo:** Device metadata and pairing information
- **SensorReading:** Historical data points with timestamps

### Firebase Integration

#### Database Paths
```
/devices/{deviceId}/
  ├─ deviceInfo/         # Device metadata
  ├─ current/            # Real-time status (updated every 5s)
  ├─ commands/           # Commands from app to device
  ├─ commandAck/         # Acknowledgments from device
  └─ history/{timestamp} # Historical data (every 30s)

/users/{userId}/
  └─ devices: [...]      # Array of paired device IDs

/devicePairing/{code}/
  ├─ deviceId
  ├─ generatedAt
  ├─ expiresAt
  └─ used
```

#### Real-time Listeners
- Device status updates (temperature, humidity, relay states)
- User's device list synchronization
- Command acknowledgment monitoring
- Historical data streaming

### UI Screens

1. **Login/Register:** Authentication with form validation
2. **Device List:** Grid of paired devices with status
3. **Dashboard:** Main control screen with gauges and controls
4. **Charts:** Historical data visualization with filters
5. **Pair Device:** 6-digit code input with visual feedback

### Local Caching

Room database entities:
- **CachedDevice:** Offline device information
- **CachedReading:** Historical sensor readings

## NTP Time Synchronization

### Overview

The ESP32 firmware uses Network Time Protocol (NTP) to synchronize time with internet time servers. This ensures accurate timestamps for all data logging, pairing code expiry, and historical data.

### Configuration

- **Timezone:** Philippines (UTC+8, no daylight saving time)
- **NTP Servers:**
  - Primary: `time.google.com`
  - Secondary: `pool.ntp.org`
  - Tertiary: `time.cloudflare.com`
- **Sync Time:** 1-10 seconds after WiFi connection

### Implementation Details

#### ESP32 Functions

```cpp
void initNTP();                    // Initialize NTP sync (called after WiFi connects)
unsigned long long getTimestamp(); // Get Unix timestamp in milliseconds
```

#### Timestamp Format
- **Type:** `unsigned long long` (64-bit)
- **Unit:** Milliseconds since Unix epoch (January 1, 1970)
- **Example:** `1700000000000` = November 14, 2023

#### Firebase Data Structure Changes

**Before NTP (using millis()):**
```json
{
  "lastUpdate": 123456789,  // Time since boot in milliseconds
  "timestamp": 987654321    // Relative time, resets on reboot
}
```

**After NTP (using real timestamps):**
```json
{
  "lastUpdate": 1700000000000,  // Unix timestamp in milliseconds
  "timestamp": 1700000000000    // Absolute time, persists across reboots
}
```

#### Updated Firebase Paths with Timestamps

**Current Status Data:**
```json
{
  "devices": {
    "{deviceId}": {
      "current": {
        "temperature": 45.5,
        "humidity": 25.3,
        "setpointTemp": 50.0,
        "setpointHumidity": 20.0,
        "relay1Status": true,
        "relay2Status": true,
        "dryingActive": true,
        "pidOutput": 75.3,
        "online": true,
        "lastUpdate": 1700000000000  // Unix timestamp in milliseconds
      }
    }
  }
}
```

**Historical Data:**
```json
{
  "devices": {
    "{deviceId}": {
      "history": {
        "1700000000": {  // Key: Unix timestamp in seconds
          "temperature": 45.5,
          "humidity": 25.3,
          "timestamp": 1700000000000,  // Unix timestamp in milliseconds
          "setpointTemp": 50.0,
          "setpointHumidity": 20.0,
          "relay1Status": true,
          "relay2Status": true
        }
      }
    }
  }
}
```

**Device Pairing with Expiry:**
```json
{
  "devicePairing": {
    "{code}": {
      "deviceId": "AABBCCDDEEFF",
      "generatedAt": 1700000000000,  // Unix timestamp in milliseconds
      "expiresAt": 1700000600000,    // generatedAt + 10 minutes
      "used": false
    }
  }
}
```

### Benefits

1. **Accurate Timestamps:** Wall-clock time instead of relative time since boot
2. **Persistent Data:** Historical data timestamps survive device reboots
3. **Cross-Device Sync:** Multiple devices show consistent times
4. **Pairing Expiry:** 10-minute pairing code expiry works correctly
5. **Time Filtering:** Charts can filter by actual time ranges
6. **Timezone Support:** Displays time in Philippines timezone (UTC+8)
7. **Data Integrity:** Timestamps remain valid across power cycles

### Fallback Mechanism

If NTP sync fails (no internet, blocked ports, DNS issues):
- System falls back to `millis()` (time since boot)
- LCD shows "Time Sync Failed, Using millis()"
- Device continues to operate normally
- Timestamps will be relative instead of absolute
- Functionality not affected, only timestamp accuracy

### LCD Status Messages

**Successful NTP Sync:**
```
WiFi Connected!
Time Synced
12/14/2025 10:30 AM
Connecting...
```

**Failed NTP Sync:**
```
WiFi Connected!
Time Sync Failed
Using millis()
Connecting...
```

### Android Integration

#### Time Display
- Historical charts show actual time (HH:mm format)
- Time range filters work with real Unix timestamps
- "Last Update" shows relative time (e.g., "5m ago", "2h ago")
- Date selectors use actual calendar dates

#### Pairing Code Validation
- Checks `expiresAt` field against current system time
- Validates 10-minute expiry window automatically
- Rejects expired codes with appropriate error message
- Regenerates codes if expired

### Testing Checklist

- [ ] Verify NTP sync message on LCD after WiFi connects
- [ ] Check that `lastUpdate` timestamps are recent Unix time (not millis)
- [ ] Confirm pairing codes expire after 10 minutes
- [ ] Test history charts show correct time labels (HH:mm format)
- [ ] Verify time range filters work (Last Hour, Last 6 Hours, etc.)
- [ ] Check device list "Last Update" shows proper time ago
- [ ] Confirm historical data survives device reboot with correct timestamps
- [ ] Test timezone display shows Philippines time (UTC+8)

## License

This project is licensed under the MIT License.

```
MIT License

Copyright (c) 2025 QPPD Development Team

Permission is hereby granted, free of charge, to any person obtaining a copy
of this software and associated documentation files (the "Software"), to deal
in the Software without restriction, including without limitation the rights
to use, copy, modify, merge, publish, distribute, sublicense, and/or sell
copies of the Software, and to permit persons to whom the Software is
furnished to do so, subject to the following conditions:

The above copyright notice and this permission notice shall be included in all
copies or substantial portions of the Software.

THE SOFTWARE IS PROVIDED "AS IS", WITHOUT WARRANTY OF ANY KIND, EXPRESS OR
IMPLIED, INCLUDING BUT NOT LIMITED TO THE WARRANTIES OF MERCHANTABILITY,
FITNESS FOR A PARTICULAR PURPOSE AND NONINFRINGEMENT. IN NO EVENT SHALL THE
AUTHORS OR COPYRIGHT HOLDERS BE LIABLE FOR ANY CLAIM, DAMAGES OR OTHER
LIABILITY, WHETHER IN AN ACTION OF CONTRACT, TORT OR OTHERWISE, ARISING FROM,
OUT OF OR IN CONNECTION WITH THE SOFTWARE OR THE USE OR OTHER DEALINGS IN THE
SOFTWARE.
```

## Contact

### Project Information

Project Name: RiceDryer ESP32 & Android IoT System
Version: 1.0 (99% Complete)
Development Team: QPPD
Repository: https://github.com/qppd/Rice-Dryer

### Support

For technical support:
- Open an issue on GitHub
- Check documentation in `/docs` folder
- Review troubleshooting section

For collaboration:
- Follow contribution guidelines
- Submit pull requests
- Join project discussions

### Documentation

- ESP32 Setup: `source/esp32/README.md`
- Android Setup: `source/android/FIREBASE_SETUP.md`
- Firebase Paths: `source/android/FIREBASE_PATH_ALIGNMENT.md`
- NTP Implementation: `source/esp32/NTP_IMPLEMENTATION.md`

### Social

- GitHub: https://github.com/qppd
- Project Repository: https://github.com/qppd/Rice-Dryer

### Acknowledgments

This project uses the following open-source libraries and services:

ESP32:
- WiFiManager by tzapu
- Firebase ESP32 Client by Mobizt
- DHT sensor library by Adafruit
- ArduinoJson by Benoit Blanchon

Android:
- Firebase by Google
- MPAndroidChart by PhilJay
- Lottie by Airbnb
- Material Components by Google
- Room Database by Google

Services:
- Firebase Realtime Database by Google
- Firebase Authentication by Google
- Firebase Cloud Messaging by Google

Special thanks to all contributors and the open-source community.

---

Project Status: Complete
Last Updated: February 10, 2026
Version: 1.0
Completion: 100%
Next Milestone: 3D Model Design

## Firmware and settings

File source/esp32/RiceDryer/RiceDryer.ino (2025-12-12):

// RiceDryer.ino
// Main Arduino sketch for RiceDryer ESP32 project

// ============================================================================
// FIRMWARE OPERATION MODE CONFIGURATION
// ============================================================================
// Uncomment the line below to enable DEVELOPMENT_MODE for isolated hardware testing
// Comment it out to use PRODUCTION_MODE (full WiFi + Firebase + PID functionality)
//
// 🔧 DEVELOPMENT_MODE:
//   - No WiFi, Firebase, or pairing required
//   - Serial command-based hardware testing only
//   - Test LCD, DHT22 sensor, and bistable relays (GPIO 19 & 18)
//   - Simple commands: LCD_TEST, DHT_READ, RELAY_HEATER_ON/OFF, RELAY_BLOWER_ON/OFF
//   - No production logic (PID, auto-stop, remote commands)
//
// 🚀 PRODUCTION_MODE (default):
//   - Full WiFi + captive portal setup
//   - Firebase real-time sync and pairing system
//   - PID temperature control with auto-stop at target humidity
//   - 3-button UI with Normal/Set Temp/Set Humidity modes
//   - Historical logging and remote commands
//   - NTP time synchronization
//   - Safety logic and sensor validation
//
// ============================================================================

//#define DEVELOPMENT_MODE  // Uncomment for testing, comment for production

// ============================================================================

#ifndef DEVELOPMENT_MODE
// WiFi and Network
#include <WiFi.h>
#include <time.h>
#include <Preferences.h>

// Firebase
#include <Firebase_ESP_Client.h>
#include <addons/TokenHelper.h>
#include <addons/RTDBHelper.h>

// Custom modules
#include "WiFiManagerCustom.h"
#include "FirebaseConfig.h"
#endif

// Include component headers (needed for both modes)
#include "Button.h"
#include "DHT22Sensor.h"
#include "SSR.h"
#include "LCDDisplay.h"
#include "TemperatureController.h"

// Pin configuration
#include "PinConfig.h"

#ifndef DEVELOPMENT_MODE
// ============================================================================
// PRODUCTION MODE - Variables and Objects
// ============================================================================

// Firebase objects
FirebaseData fbdo;
FirebaseAuth auth;
FirebaseConfig config;

// WiFi Manager
WiFiManagerCustom wifiManager;

// Preferences for persistent storage
Preferences preferences;

// Device Information
String deviceId;
String pairingCode = "";
bool devicePaired = false;
unsigned long long pairingCodeExpiry = 0;  // Changed to unsigned long long for Unix timestamps

// LCD state tracking to prevent flickering
String lastLcdLine0 = "";
String lastLcdLine1 = "";
String lastLcdLine2 = "";
String lastLcdLine3 = "";

// Components
Button button1(BUTTON_1);
Button button2(BUTTON_2);
Button button3(BUTTON_3);
DHT22Sensor dht(DHT_PIN);
SSR relay1(RELAY_1);
SSR relay2(RELAY_2);
LCDDisplay lcd(LCD_ADDR, LCD_COLS, LCD_ROWS);
TemperatureController tempController;

// Legacy compatibility
Button& button = button1;  // Reference to first button for existing code
SSR& ssr = relay1;         // Reference to first relay for existing code

// Logic variables
bool dryingActive = false;
unsigned long lastSensorRead = 0;
unsigned long lastFirebaseUpdate = 0;
unsigned long lastHistoryLog = 0;
unsigned long lastCommandCheck = 0;
const unsigned long SENSOR_INTERVAL = 2000; // ms
const unsigned long FIREBASE_UPDATE_INTERVAL = 5000; // 5 seconds
const unsigned long HISTORY_LOG_INTERVAL = 30000; // 30 seconds
const unsigned long COMMAND_CHECK_INTERVAL = 1000; // 1 second
const unsigned long PAIRING_CODE_VALIDITY = 600000; // 10 minutes

float temperature = 0.0;
float humidity = 0.0;
float setpointTemp = 40.0;     // Default target temperature
float setpointHumidity = 20.0; // Default target humidity (stop when reached)
bool wifiConnected = false;
bool firebaseConnected = false;

// Button adjustment settings
const float TEMP_STEP = 1.0;      // Temperature adjustment increment (1°C)
const float HUMIDITY_STEP = 1.0;  // Humidity adjustment increment (1%)
const float TEMP_MIN = 30.0;
const float TEMP_MAX = 80.0;
const float HUMIDITY_MIN = 10.0;
const float HUMIDITY_MAX = 50.0;

// UI and control states
enum SettingMode {
  NORMAL_MODE,
  SET_TEMP_MODE,
  SET_HUMIDITY_MODE
};

SettingMode currentMode = NORMAL_MODE;
unsigned long modeStartTime = 0;
const unsigned long MODE_TIMEOUT = 5000; // 5 seconds timeout for setting modes

// Button states for debouncing
bool button1LastState = false;
bool button2LastState = false;
bool button3LastState = false;
unsigned long button1LastPress = 0;
unsigned long button2LastPress = 0;
unsigned long button3LastPress = 0;

const unsigned long BUTTON_DEBOUNCE = 200; // 200ms debounce

#endif

// Generate unique device ID from MAC address
String getDeviceId() {
  uint8_t mac[6];
  WiFi.macAddress(mac);
  char macStr[18];
  snprintf(macStr, sizeof(macStr), "%02X%02X%02X%02X%02X%02X",
           mac[0], mac[1], mac[2], mac[3], mac[4], mac[5]);
  return String(macStr);
}

// Generate random 6-digit pairing code
String generatePairingCode() {
  String code = "";
  for (int i = 0; i < 6; i++) {
    code += String(random(0, 10));
  }
  return code;
}

// Initialize WiFi with WiFiManager
bool initWiFi() {
  lcd.clear();
  lcd.print(0, 0, "WiFi Setup");
  lcd.print(0, 1, "Connect to AP");
  
  if (!wifiManager.begin("RiceDryer_Setup", "password123")) {
    lcd.clear();
    lcd.print(0, 0, "WiFi Failed!");
    lcd.print(0, 1, "Restarting...");
    delay(3000);
    ESP.restart();
    return false;
  }
  
  lcd.clear();
  lcd.print(0, 0, "WiFi Connected!");
  lcd.print(0, 1, wifiManager.getLocalIP().c_str());
  delay(2000);
  
  wifiConnected = true;
  
  // Initialize NTP for real timestamps
  initNTP();
  
  return true;
}

// Initialize NTP (Network Time Protocol) for Philippines timezone
void initNTP() {
  lcd.clear();
  lcd.print(0, 0, "Syncing Time...");
  
  // Philippines timezone: UTC+8, no DST
  // NTP servers for Philippines
  configTime(8 * 3600, 0, "time.google.com", "pool.ntp.org", "time.cloudflare.com");
  
  // Wait for time to be set
  int retries = 0;
  while (time(nullptr) < 100000 && retries < 20) {
    delay(500);
    Serial.print(".");
    retries++;
  }
  
  if (time(nullptr) > 100000) {
    lcd.clear();
    lcd.print(0, 0, "Time Synced!");
    struct tm timeinfo;
    if (getLocalTime(&timeinfo)) {
      char timeStr[20];
      strftime(timeStr, sizeof(timeStr), "%Y-%m-%d %H:%M", &timeinfo);
      lcd.print(0, 1, timeStr);
      Serial.println("\nNTP time synchronized: " + String(timeStr));
    }
    delay(2000);
  } else {
    lcd.clear();
    lcd.print(0, 0, "Time Sync Failed");
    lcd.print(0, 1, "Using millis()");
    Serial.println("\nNTP sync failed, will use millis()");
    delay(2000);
  }
}

// Get current Unix timestamp in milliseconds
unsigned long long getTimestamp() {
  struct timeval tv;
  gettimeofday(&tv, NULL);
  unsigned long long timestamp = (unsigned long long)(tv.tv_sec) * 1000ULL + (tv.tv_usec / 1000ULL);
  
  // If NTP hasn't synced yet, fall back to millis()
  if (timestamp < 1000000000000ULL) {
    return millis();
  }
  
  return timestamp;
}

// Initialize Firebase connection
bool initFirebase() {
  lcd.clear();
  lcd.print(0, 0, "Connecting to");
  lcd.print(0, 1, "Firebase...");
  
  config.host = RiceDryerConfig::getFirebaseHost();
  config.signer.tokens.legacy_token = RiceDryerConfig::getFirebaseAuth();
  config.database_url = RiceDryerConfig::getDatabaseURL();
  config.timeout.serverResponse = 10 * 1000;
  
  Firebase.begin(&config, &auth);
  Firebase.reconnectWiFi(true);
  
  if (Firebase.ready()) {
    lcd.clear();
    lcd.print(0, 0, "Firebase Ready!");
    delay(1000);
    firebaseConnected = true;
    
    // Register device
    registerDevice();
    return true;
  } else {
    lcd.clear();
    lcd.print(0, 0, "Firebase Failed!");
    delay(2000);
    return false;
  }
}

// Register device in Firebase
void registerDevice() {
  String path = "/devices/" + deviceId + "/deviceInfo";
  FirebaseJson json;
  json.set("macAddress", deviceId);
  json.set("firmwareVersion", "1.0.0");
  json.set("hardwareVersion", "1.0");
  json.set("lastBoot", (double)getTimestamp());  // Use NTP timestamp
  
  if (Firebase.RTDB.setJSON(&fbdo, path.c_str(), &json)) {
    Serial.println("Device registered successfully");
  } else {
    Serial.println("Device registration failed: " + fbdo.errorReason());
  }
  
  // Check if device is paired
  checkPairingStatus();
}

// Check if device is already paired
void checkPairingStatus() {
  // First check local storage (persists across reboots)
  preferences.begin("ricedryer", false);
  bool localPaired = preferences.getBool("paired", false);
  String localUserId = preferences.getString("userId", "");
  preferences.end();
  
  if (localPaired && localUserId != "") {
    // Device was paired before - verify with Firebase
    String path = "/devices/" + deviceId + "/deviceInfo/pairedTo";
    if (Firebase.RTDB.getString(&fbdo, path.c_str())) {
      String pairedTo = fbdo.stringData();
      
      // Check if still paired to the same user
      if (pairedTo == localUserId) {
        devicePaired = true;
        lcd.clear();
        lcd.print(0, 0, "Device Paired!");
        lcd.print(0, 1, "Ready to use");
        Serial.println("Device already paired to: " + localUserId);
        delay(1000);
        return;
      } else if (pairedTo == "" || pairedTo == "null") {
        // Unpaired on Firebase - clear local storage
        Serial.println("Device was unpaired remotely");
        clearPairingData();
      } else {
        // Paired to different user - clear and re-pair
        Serial.println("Device paired to different user, clearing local data");
        clearPairingData();
      }
    }
  }
  
  // Not paired locally or verification failed - check Firebase
  String path = "/devices/" + deviceId + "/deviceInfo/pairedTo";
  if (Firebase.RTDB.getString(&fbdo, path.c_str())) {
    String pairedTo = fbdo.stringData();
    if (pairedTo != "" && pairedTo != "null") {
      // Paired on Firebase but not locally - save to local storage
      devicePaired = true;
      savePairingData(pairedTo);
      lcd.clear();
      lcd.print(0, 0, "Device Paired!");
      lcd.print(0, 1, "Synced from cloud");
      Serial.println("Pairing synced from Firebase: " + pairedTo);
      delay(1000);
    } else {
      // Not paired - generate pairing code
      startPairingMode();
    }
  }
}

// Save pairing data to persistent storage
void savePairingData(String userId) {
  preferences.begin("ricedryer", false);
  preferences.putBool("paired", true);
  preferences.putString("userId", userId);
  preferences.end();
  Serial.println("Pairing data saved to flash: " + userId);
}

// Clear pairing data from persistent storage
void clearPairingData() {
  preferences.begin("ricedryer", false);
  preferences.putBool("paired", false);
  preferences.putString("userId", "");
  preferences.end();
  devicePaired = false;
  Serial.println("Pairing data cleared from flash");
}

// Start pairing mode
void startPairingMode() {
  pairingCode = generatePairingCode();
  unsigned long long currentTime = getTimestamp();
  pairingCodeExpiry = currentTime + PAIRING_CODE_VALIDITY;
  
  // Store pairing code in Firebase
  String path = "/devicePairing/" + pairingCode;
  FirebaseJson json;
  json.set("deviceId", deviceId);
  json.set("generatedAt", (double)currentTime);
  json.set("expiresAt", (double)pairingCodeExpiry);
  json.set("used", false);
  
  Firebase.RTDB.setJSON(&fbdo, path.c_str(), &json);
  
  Serial.println("Pairing mode started - Code: " + pairingCode);
  lcd.clear();
  lcd.print(0, 0, "Pairing Code:");
  lcd.print(0, 1, pairingCode.c_str());
  lcd.print(0, 2, "MAC Address:");
  lcd.print(0, 3, deviceId.c_str());
}

// Send data to Firebase
void sendDataToFirebase() {
  if (!firebaseConnected || !devicePaired) return;
  
  String path = "/devices/" + deviceId + "/current";
  FirebaseJson json;
  json.set("temperature", temperature);
  json.set("humidity", humidity);
  json.set("setpointTemp", setpointTemp);
  json.set("setpointHumidity", setpointHumidity);
  json.set("relay1Status", relay1.isOn());
  json.set("relay2Status", relay2.isOn());
  json.set("dryingActive", dryingActive);
  json.set("currentMode", (int)currentMode);
  json.set("pidOutput", tempController.getOutput());
  json.set("online", true);
  json.set("lastUpdate", (double)getTimestamp());  // Use NTP timestamp
  
  if (!Firebase.RTDB.setJSON(&fbdo, path.c_str(), &json)) {
    Serial.println("Failed to send data: " + fbdo.errorReason());
  }
}

// Log historical data
void logHistoricalData() {
  if (!firebaseConnected || !devicePaired) return;
  
  unsigned long long timestamp = getTimestamp();
  String path = "/devices/" + deviceId + "/history/" + String((unsigned long)(timestamp / 1000));  // Use seconds for key
  
  FirebaseJson json;
  json.set("temperature", temperature);
  json.set("humidity", humidity);
  json.set("setpointTemp", setpointTemp);
  json.set("setpointHumidity", setpointHumidity);
  json.set("relay1Status", relay1.isOn());
  json.set("relay2Status", relay2.isOn());
  json.set("dryingActive", dryingActive);
  json.set("pidOutput", tempController.getOutput());
  json.set("timestamp", (double)timestamp);  // Also include timestamp in the data
  
  if (!Firebase.RTDB.setJSON(&fbdo, path.c_str(), &json)) {
    Serial.println("Failed to log history: " + fbdo.errorReason());
  }
}

// Check for remote commands
void checkRemoteCommands() {
  if (!firebaseConnected || !devicePaired) return;
  
  String path = "/devices/" + deviceId + "/commands";
  if (Firebase.RTDB.getJSON(&fbdo, path.c_str())) {
    FirebaseJson &json = fbdo.jsonObject();
    FirebaseJsonData jsonData;
    
    // Check for START command
    if (json.get(jsonData, "action")) {
      String action = jsonData.stringValue;
      
      if (action == "START") {
        dryingActive = true;
        acknowledgeCommand("START");
      } else if (action == "STOP") {
        dryingActive = false;
        acknowledgeCommand("STOP");
      } else if (action == "SET_TEMP") {
        if (json.get(jsonData, "value")) {
          setpointTemp = jsonData.floatValue;
          tempController.setSetpoint(setpointTemp);  // Update PID setpoint
          acknowledgeCommand("SET_TEMP");
        }
      } else if (action == "SET_HUMIDITY") {
        if (json.get(jsonData, "value")) {
          setpointHumidity = jsonData.floatValue;
          acknowledgeCommand("SET_HUMIDITY");
        }
      }
      
      // Clear command
      Firebase.RTDB.deleteNode(&fbdo, path.c_str());
    }
  }
}

// Acknowledge command execution
void acknowledgeCommand(String command) {
  String path = "/devices/" + deviceId + "/commandAck";
  FirebaseJson json;
  json.set("command", command);
  json.set("timestamp", (double)getTimestamp());  // Use NTP timestamp
  json.set("acknowledged", true);
  
  Firebase.RTDB.setJSON(&fbdo, path.c_str(), &json);
}

void testDHT22() {
  lcd.clear();
  lcd.print(0, 0, "Testing DHT22...");
  float t = dht.readTemperature();
  float h = dht.readHumidity();
  char buf[17];
  snprintf(buf, sizeof(buf), "T:%2.1f H:%2.1f", t, h);
  lcd.print(0, 1, String(buf));
  delay(2000);
}



void testSSR() {
  lcd.clear();
  lcd.print(0, 0, "Testing Relay1...");
  lcd.print(0, 1, "ON for 2s");
  relay1.on();
  delay(2000);
  lcd.print(0, 1, "OFF for 2s");
  relay1.off();
  delay(1000);
  
  lcd.print(0, 0, "Testing Relay2...");
  lcd.print(0, 1, "ON for 2s");
  relay2.on();
  delay(2000);
  lcd.print(0, 1, "OFF for 2s");
  relay2.off();
  delay(2000);
}

void testLCD() {
  lcd.clear();
  lcd.print(0, 0, "Testing LCD...");
  lcd.print(0, 1, "Hello World!");
  delay(2000);
  lcd.clear();
}

// Handle button press with debouncing
bool isButtonPressed(Button& button, bool& lastState, unsigned long& lastPress) {
  bool currentState = button.isPressed();
  bool pressed = false;
  
  if (currentState && !lastState && (millis() - lastPress > BUTTON_DEBOUNCE)) {
    pressed = true;
    lastPress = millis();
  }
  
  lastState = currentState;
  return pressed;
}

// Handle button-based setpoint adjustment
void handleSetpointAdjustment() {
  // Button 2: Increase setpoint
  if (isButtonPressed(button2, button2LastState, button2LastPress)) {
    switch (currentMode) {
      case SET_TEMP_MODE:
        setpointTemp += TEMP_STEP;
        if (setpointTemp > TEMP_MAX) setpointTemp = TEMP_MAX;
        tempController.setSetpoint(setpointTemp);
        modeStartTime = millis(); // Reset timeout when adjusting
        break;
      case SET_HUMIDITY_MODE:
        setpointHumidity += HUMIDITY_STEP;
        if (setpointHumidity > HUMIDITY_MAX) setpointHumidity = HUMIDITY_MAX;
        modeStartTime = millis(); // Reset timeout when adjusting
        break;
      case NORMAL_MODE:
        // In normal mode, button 2 starts/stops drying (handled elsewhere)
        break;
    }
  }
  
  // Button 3: Decrease setpoint
  if (currentMode != NORMAL_MODE && isButtonPressed(button3, button3LastState, button3LastPress)) {
    switch (currentMode) {
      case SET_TEMP_MODE:
        setpointTemp -= TEMP_STEP;
        if (setpointTemp < TEMP_MIN) setpointTemp = TEMP_MIN;
        tempController.setSetpoint(setpointTemp);
        modeStartTime = millis(); // Reset timeout when adjusting
        break;
      case SET_HUMIDITY_MODE:
        setpointHumidity -= HUMIDITY_STEP;
        if (setpointHumidity < HUMIDITY_MIN) setpointHumidity = HUMIDITY_MIN;
        modeStartTime = millis(); // Reset timeout when adjusting
        break;
      default:
        break;
    }
  }
}

// Reset WiFi credentials and restart
void resetWiFiCredentials() {
  lcd.clear();
  lcd.print(0, 0, "Resetting WiFi...");
  lcd.print(0, 1, "Please wait...");
  
  wifiManager.reset();
  delay(2000);
  
  lcd.clear();
  lcd.print(0, 0, "WiFi Reset!");
  lcd.print(0, 1, "Restarting...");
  delay(2000);
  
  ESP.restart();
}

// Factory reset - clear all stored data
void factoryReset() {
  lcd.clear();
  lcd.print(0, 0, "Factory Reset");
  lcd.print(0, 1, "Clearing data...");
  
  // Clear pairing data
  clearPairingData();
  
  // Clear WiFi credentials
  wifiManager.reset();
  
  delay(2000);
  lcd.clear();
  lcd.print(0, 0, "Reset Complete!");
  lcd.print(0, 1, "Restarting...");
  delay(2000);
  
  ESP.restart();
}

// Check if humidity target is reached (dryer should stop)
bool isHumidityTargetReached() {
  return humidity <= setpointHumidity;
}

// Control drying logic
void controlDrying() {
  // ALWAYS turn off relays first if drying is not active
  if (!dryingActive) {
    // Force turn off all heating and disable PID when not drying
    relay1.off();
    relay2.off();
    tempController.setMode(false);  // Set PID to manual mode
    return;
  }
  
  // Enable PID when drying is active
  tempController.setMode(true);  // Set PID to automatic mode
  
  // Check if humidity target is reached
  if (isHumidityTargetReached()) {
    dryingActive = false;
    relay1.off();
    relay2.off();
    tempController.setMode(false);  // Disable PID
    
    // Display completion message
    lcd.clear();
    lcd.print(0, 0, "Drying Complete!");
    lcd.print(0, 1, "Target Reached");
    delay(2000);
    return;
  }
  
  // Update PID controller with current temperature and compute output
  bool pidComputed = tempController.compute(temperature);
  
  if (pidComputed) {
    // Get PID recommendation for heater control
    bool shouldHeat = tempController.shouldHeatOn();
    double pidOutput = tempController.getOutput();
    
    // Control relay1 (main heater) based on PID output
    if (shouldHeat && dryingActive) {  // Double-check dryingActive
      relay1.on();
      Serial.print("PID Heating ON - Output: ");
      Serial.print(pidOutput);
      Serial.println("%");
    } else {
      relay1.off();
      Serial.print("PID Heating OFF - Output: ");
      Serial.print(pidOutput);
      Serial.println("%");
    }
    
    // Only run fan (relay2) during active drying for air circulation
    if (dryingActive) {
      relay2.on();
    } else {
      relay2.off();
    }
  } else {
    // If PID didn't compute, ensure relays are off when not drying
    if (!dryingActive) {
      relay1.off();
      relay2.off();
    }
  }
}

// Update LCD display based on current mode
void updateDisplay() {
  String line0 = "";
  String line1 = "";
  String line2 = "";
  String line3 = "";
  
  switch (currentMode) {
    case SET_TEMP_MODE:
      line0 = "Set Temperature:";
      line1 = String(setpointTemp, 1) + "C";
      line2 = "Btn2:+ Btn3:-";
      break;
      
    case SET_HUMIDITY_MODE:
      line0 = "Set Humidity:";
      line1 = String(setpointHumidity, 1) + "%";
      line2 = "Btn2:+ Btn3:-";
      break;
      
    default: // NORMAL_MODE
      line0 = dryingActive ? "Drying: ON " : "Drying: OFF";
      char buf[21];
      snprintf(buf, sizeof(buf), "T:%2.1f H:%2.1f", temperature, humidity);
      line1 = String(buf);
      break;
  }
  
  // Only update lines that changed
  if (line0 != lastLcdLine0) {
    lcd.print(0, 0, "                    "); // Clear line with spaces
    lcd.print(0, 0, line0.c_str());
    lastLcdLine0 = line0;
  }
  if (line1 != lastLcdLine1) {
    lcd.print(0, 1, "                    ");
    lcd.print(0, 1, line1.c_str());
    lastLcdLine1 = line1;
  }
  if (line2 != lastLcdLine2) {
    lcd.print(0, 2, "                    ");
    lcd.print(0, 2, line2.c_str());
    lastLcdLine2 = line2;
  }
  if (line3 != lastLcdLine3) {
    lcd.print(0, 3, "                    ");
    lcd.print(0, 3, line3.c_str());
    lastLcdLine3 = line3;
  }
}
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
void loop() {
#ifdef DEVELOPMENT_MODE
  // Should never reach here (runDevelopmentMode has infinite loop)
  // But just in case:
  delay(1000);
#else
  // Production mode: Main control loop
  productionLoop();
#endif
}

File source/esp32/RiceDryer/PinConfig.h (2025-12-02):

// PinConfig.h
// Centralized pin configuration for RiceDryer ESP32

#ifndef PINCONFIG_H
#define PINCONFIG_H

// Button pins (input with internal pull-up)
const uint8_t BUTTON_1 = 17;
const uint8_t BUTTON_2 = 16;
const uint8_t BUTTON_3 = 4;

// Relay pins (output)
const uint8_t RELAY_1 = 19;
const uint8_t RELAY_2 = 18;

// DHT22 sensor pin
const uint8_t DHT_PIN = 23;

// LCD configuration
const uint8_t LCD_ADDR = 0x27;
const uint8_t LCD_COLS = 20;
const uint8_t LCD_ROWS = 4;

// Legacy compatibility (for existing code that uses these names)
const uint8_t BUTTON_PIN = BUTTON_1;  // Default to first button
const uint8_t SSR_PIN = RELAY_1;     // Default to first relay

#endif // PINCONFIG_H

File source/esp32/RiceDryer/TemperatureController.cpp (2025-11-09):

#include "TemperatureController.h"
#include <Arduino.h>

// Static constants
const double TemperatureController::OUTPUT_MIN = 0.0;
const double TemperatureController::OUTPUT_MAX = 100.0;
const double TemperatureController::HEATING_THRESHOLD = 10.0; // Turn on heater if output > 10%

TemperatureController::TemperatureController() {
    // Initialize variables
    currentTemperature = 0.0;
    temperatureSetpoint = 40.0;  // Default setpoint
    pidOutput = 0.0;
    
    // Default PID parameters (tuned for rice dryer system)
    // These values may need adjustment based on your specific heating system
    kp = 2.0;   // Proportional gain - how aggressively to respond to current error
    ki = 0.1;   // Integral gain - how aggressively to respond to historic error
    kd = 0.5;   // Derivative gain - how aggressively to respond to rate of error change
    
    // Create PID controller instance
    pidController = new PID(&currentTemperature, &pidOutput, &temperatureSetpoint, kp, ki, kd, DIRECT);
}

void TemperatureController::begin() {
    // Set PID to automatic mode
    pidController->SetMode(AUTOMATIC);
    
    // Set output limits (0-100%)
    pidController->SetOutputLimits(OUTPUT_MIN, OUTPUT_MAX);
    
    // Set sample time (how often to compute - 1000ms = 1 second)
    pidController->SetSampleTime(1000);
    
    Serial.println("Temperature PID Controller initialized");
    Serial.print("PID Parameters - Kp: ");
    Serial.print(kp);
    Serial.print(", Ki: ");
    Serial.print(ki);
    Serial.print(", Kd: ");
    Serial.println(kd);
}

void TemperatureController::setPIDParameters(double newKp, double newKi, double newKd) {
    kp = newKp;
    ki = newKi;
    kd = newKd;
    
    // Update PID controller with new parameters
    pidController->SetTunings(kp, ki, kd);
    
    Serial.print("PID Parameters updated - Kp: ");
    Serial.print(kp);
    Serial.print(", Ki: ");
    Serial.print(ki);
    Serial.print(", Kd: ");
    Serial.println(kd);
}

void TemperatureController::setSetpoint(double setpoint) {
    temperatureSetpoint = setpoint;
    Serial.print("Temperature setpoint changed to: ");
    Serial.print(setpoint);
    Serial.println("°C");
}

bool TemperatureController::compute(double currentTemp) {
    // Update current temperature
    currentTemperature = currentTemp;
    
    // Validate temperature reading
    if (isnan(currentTemp) || currentTemp < -50 || currentTemp > 150) {
        Serial.println("Invalid temperature reading for PID");
        return false;
    }
    
    // Compute PID output
    bool computed = pidController->Compute();
    
    if (computed) {
        Serial.print("PID Compute - Temp: ");
        Serial.print(currentTemp);
        Serial.print("°C, Setpoint: ");
        Serial.print(temperatureSetpoint);
        Serial.print("°C, Output: ");
        Serial.print(pidOutput);
        Serial.println("%");
    }
    
    return computed;
}

double TemperatureController::getOutput() {
    return pidOutput;
}

double TemperatureController::getSetpoint() {
    return temperatureSetpoint;
}

void TemperatureController::setMode(bool automatic) {
    if (automatic) {
        pidController->SetMode(AUTOMATIC);
        Serial.println("PID Controller set to AUTOMATIC mode");
    } else {
        pidController->SetMode(MANUAL);
        Serial.println("PID Controller set to MANUAL mode");
    }
}

bool TemperatureController::shouldHeatOn() {
    // Turn on heater if PID output is above threshold
    bool heatOn = pidOutput > HEATING_THRESHOLD;
    
    // Additional safety check - don't heat if already above setpoint + 2°C (overshoot protection)
    if (currentTemperature > (temperatureSetpoint + 2.0)) {
        heatOn = false;
        Serial.println("Overshoot protection: Heater disabled");
    }
    
    return heatOn;
}

void TemperatureController::reset() {
    // Reset integral term to prevent windup
    pidController->SetMode(MANUAL);
    pidOutput = 0.0;
    pidController->SetMode(AUTOMATIC);
    
    Serial.println("PID Controller reset (integral windup cleared)");
}

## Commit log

2025-10-18 Add solar power, battery, and MPPT solar charging details to README.md
2025-10-18 Refactor: separate pin configuration to PinConfig.h and add component test mode
2025-10-18 docs: update README.md for pin config and test mode features
2025-10-24 Consolidate documentation and implement security system
    - Consolidated 7 MD files into single comprehensive README.md (1825 lines)
    - Removed all emojis and icons for professional presentation
    - Implemented modular credential management for ESP32 (FirebaseConfig)
    - Created WiFiManagerCustom wrapper for WiFi management
    - Added multi-layer .gitignore protection (root/ESP32/Android)
    - Created template files for secure credential setup
    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
2025-11-09 Enhanced ESP32 Rice Dryer: 3-button interface, dual relay control, and humidity-based auto-stop
    - Updated pin configuration for ESP32 38-pin dev module
    - Button 1 (GPIO 17): Setting mode toggle (temp/humidity)
    - Button 2 (GPIO 16): Start/stop drying control
    - Button 3 (GPIO 4): WiFi credentials reset (hold 3s)
    - Dual relay system: GPIO 19 (heater), GPIO 18 (fan)
    - Potentiometer (GPIO 34): Dynamic setpoint adjustment
    - DHT22 sensor (GPIO 39): Optimized input-only pin
    - Smart drying logic: Auto-stop when humidity target reached
    - Enhanced safety features and user interface
    - Updated README with comprehensive usage guide
    [PinConfig.h, RiceDryer.ino]
2025-11-09 Implement PID Temperature Control for Rice Dryer
    - Added TemperatureController.h/.cpp with professional PID control
    - Replaced simple on/off heating with smooth PID regulation
    - Features: Overshoot protection, integral windup prevention, tunable parameters
    - Default PID parameters: Kp=2.0, Ki=0.1, Kd=0.5 (optimized for heating systems)
    - Smart mode switching: PID enables/disables with drying state
    - Enhanced Firebase logging: PID output percentage included
    - Real-time setpoint updates: Potentiometer and remote control sync PID
    - Safety features: Temperature validation, 10% heating threshold
    - Serial debugging: Detailed PID computation logging
    - Requires PID_v1 library installation in Arduino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
    [RiceDryer.ino, TemperatureController.cpp]
2025-11-09 Fix compilation errors for ESP32 Rice Dryer
    - Added missing Arduino.h includes to all header files (Button.h, Potentiometer.h, SSR.h, DHT22Sensor.h, LCDDisplay.h)
    - Renamed FirebaseConfig class to RiceDryerConfig to avoid conflict with Firebase library typedef
    - Fixed WiFiManager method call: resetSettings() -> reset() to match custom implementation
    - Standardized pin definitions: Changed #define to const uint8_t for consistency
    - Updated all references to use RiceDryerConfig instead of FirebaseConfig
    - All component headers now properly include Arduino.h for uint8_t type definitions
    [PinConfig.h, RiceDryer.ino]
2025-11-14 Complete Android app implementation with NTP time sync
    Major Features Added:
    - Full Android application with MVVM architecture
    - Complete authentication system (login, register, password reset)
    - Device list management with real-time status updates
    - Interactive dashboard with animated gauges and controls
    - Historical data charts with time range filtering
    - Device pairing with 6-digit code validation
    - NTP time synchronization for ESP32 (Philippines UTC+8)
    Android App Implementation:
    - Jetpack Compose UI with Material Design 3
    - Firebase Realtime Database integration
    - Room database for offline caching
    - MPAndroidChart for data visualization
    - Navigation Compose for screen routing
    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
2025-11-14 feat: Implement brand identity with logo integration and custom color theme
    Brand Design Implementation:
    - Extract color palette from logo.png (golden amber, rice brown, warm orange)
    - Create comprehensive brand color system with light/dark variants
    - Implement custom Material 3 color schemes for light and dark modes
    - Disable dynamic colors to maintain consistent brand identity
    Color System (Color.kt):
    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
2025-11-14 build: Add debug APK build for Rice Dryer Android app
    APK Details:
    - Debug build of Rice Dryer Android application
    - Includes brand identity implementation (logo and custom theme)
    - Features: Firebase auth, device management, real-time monitoring
    - Location: source/android/RiceDryer/app/build/outputs/apk/debug/RiceDryer.apk
    Build includes all recent features:
    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
2025-12-01 Complete Rice Dryer IoT System - 99% Complete
    ESP32 Firmware Enhancements:
    - Updated LCD to 20x4 display with improved pairing mode
    - Added MAC address display below pairing code for easier device identification
    - Implemented low-trigger SSR support for latching/bistable relays
    - Eliminated LCD flickering with smart state tracking and selective updates
    - Enhanced pairing code generation and display logic
    Android Application Fixes:
    - Fixed NegativeArraySizeException in charts by adding data validation
    - Improved chart stability with finite value checks and range validation
    - Fixed device pairing button enable/disable logic (trimmed whitespace issues)
    - Enhanced chart rendering with proper er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
    [RiceDryer.ino, SSR.cpp]
2025-12-02 Update README.md with detailed component specifications, Lazada source links for all electronics and hardware components, updated last modified date, and added salvaged/modified heating element detai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
2025-12-02 Update cost estimates in README.md: corrected plywood to 980, tek screws to 50, nails to 50, added hinges (2 pcs at 70 each = 140), adjusted mechanical enclosure cost to 1,670-2,000, and updated tota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
2025-12-12 Add wiring diagram files and update README with circuit diagram
    [Wiring.fzz]
2025-12-12 Add 3D model images and update README with enclosure views
    [Wiring.fzz]
2026-02-10 Consolidate documentation: Update README.md with ESP32 firmware details and delete redundant MD files
    - Enhanced README.md with comprehensive ESP32 firmware documentation
    - Added ESP32 operation modes (Development/Production) with detailed guides
    - Included code size optimization notes and partition scheme fixes
    - Added NTP time synchronization implementation details
    - Consolidated ESP32 code flow diagrams and version history
    - Enhanced troubleshooting section with compilation fixes
    - Removed 14 redundant MD files from source/esp32/ and source/android/
    - Maintained root README.md structure and organization
